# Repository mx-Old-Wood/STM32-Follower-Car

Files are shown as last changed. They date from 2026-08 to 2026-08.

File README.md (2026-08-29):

# STM32 双车跟随小车

基于 STM32F103C8T6 的双车协同跟随项目。本仓库收录从车控制固件、STM32 控制板和双路 DRV8701 电机驱动板设计，覆盖红外循迹、车辆测距、双车通信、串级闭环调速及分阶段超车控制。

## 实物展示

<p align="center">
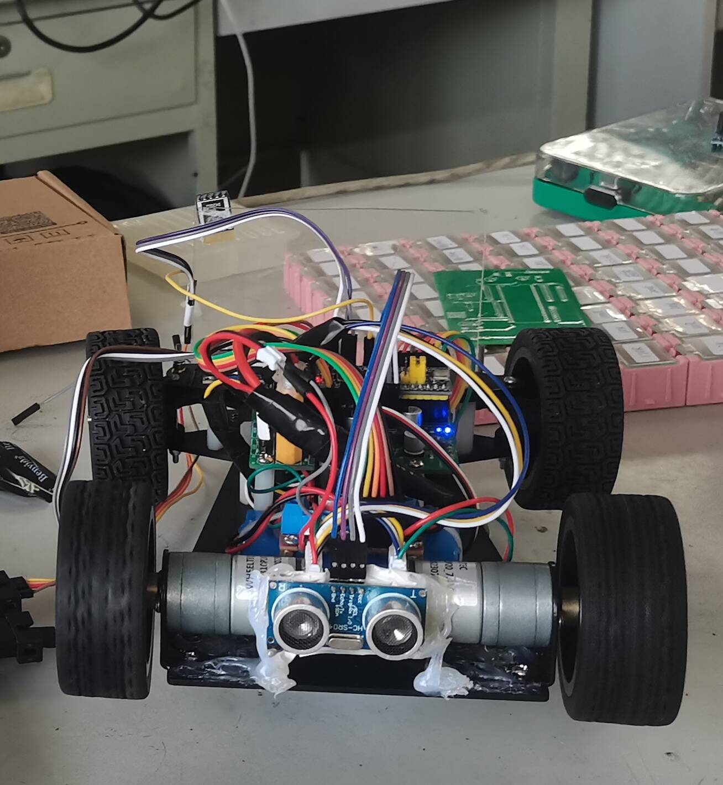
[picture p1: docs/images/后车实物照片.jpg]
STM32 双车跟随小车后车实物
  
</p>

<p align="center">后车实物照片</p>

## 项目概览

从车通过五路红外传感器识别赛道，通过本车超声波或另一辆车发送的距离信息确定跟车速度。距离 P 控制器生成直行速度设定值，双路编码器 PI 控制器进一步调节左右电机 PWM，构成距离外环与速度内环组合的串级控制链路。

模式 2 使用赛道圈数标志 `finish` 描述双车相对位置的变化：从车首先在后方跟随，完成超车后切换为串口距离闭环，另一辆车再次超车后恢复本车超声波闭环。

## 系统架构

```mermaid
flowchart LR
    IR[五路红外传感器] --> TRACK[循迹与转向决策]
    US[本车超声波] --> SELECT[距离源选择]
    UART[另一辆车串口距离] --> SELECT
    FINISH[finish 阶段标志] --> SELECT
    SELECT --> OUTER[距离 P 外环]
    OUTER --> TARGET[直行速度设定]
    TRACK --> MOTION[运动控制]
    TARGET --> MOTION
    MOTION --> PI[双电机增量式 PI]
    PI --> PWM[PWM / DRV8701]
    PWM --> MOTOR[左右直流电机]
    MOTOR --> ENCODER[编码器测速]
    ENCODER --> PI
```

循迹转向采用固定差速参数，距离外环主要作用于直行阶段的速度设定。

## 功能组成

- 五路红外循迹与赛道标志线识别。
- 本车超声波距离和串口距离双数据源切换。
- `20~400 mm` 距离有效范围判断与异常数据剔除。
- 目标距离 `200 mm` 的距离 P 外环。
- `10 ms` 更新周期的双电机增量式 PI 速度内环。
- 基于 `finish` 阶段标志的跟随、超车与让行速度策略。
- OLED 距离/轮速显示，以及停车状态蜂鸣器提示。

## 控制阶段

| 工作状态 | 距离反馈 | 距离失效时的速度策略 |
| --- | --- | --- |
| 模式 1、模式 3 | 本车超声波 | 基础速度 40 |
| 模式 2，`finish == 0` | 本车超声波 | 基础速度 40 |
| 模式 2，`finish == 1` | 串口距离 | 找到车辆前为 45，找到后为 40 |
| 模式 2，`finish >= 2` | 本车超声波 | 找到车辆前为 35，找到后为 40 |

## 硬件设计

| 板卡 | 主要内容 | 设计资料 |
| --- | --- | --- |
| STM32 控制板 | STM32 核心板接口、电源、红外、超声波、串口、蜂鸣器和电机控制接口 | [原理图](docs/images/主控板原理图.pdf) · [布线图](docs/images/主控板布线图.pdf) · [丝印图](docs/images/主控板丝印图.pdf) |
| 双路 DRV8701 驱动板 | 双路栅极驱动、外置功率 MOSFET、逻辑缓冲、电源稳压和状态指示 | [原理图](docs/images/驱动板原理图.pdf) · [布线图](docs/images/驱动板布线图.pdf) · [丝印图](docs/images/驱动板丝印图.pdf) |

Altium Designer 源文件分别位于 [控制板目录](hardware/controller-board/README.md) 和 [驱动板目录](hardware/dual-drv8701/README.md)。

## 软件结构

```text
firmware/follower/
├─ User/                主循环、模式切换与距离控制
├─ Hardware/            红外、超声波、编码器、电机、串口和显示驱动
├─ System/PID/          双电机增量式 PI
├─ System/Timer/        超声波计时、轮速计算和控制周期调度
├─ Library/             STM32F10x 标准外设库
└─ Project.uvprojx      Keil uVision 工程
```

## 构建与验证

| 项目 | 配置 |
| --- | --- |
| MCU | STM32F103C8T6 |
| IDE | Keil uVision 5.41 |
| 编译器 | ARM Compiler 5.06 update 5 (build 528) |
| Device Pack | STM32F1xx DFP 2.2.0 |
| 工程目标 | `Target 1` |
| 构建结果 | `0 Error(s), 0 Warning(s)` |

当前版本完成了源码和工程配置的全量编译验证。原项目曾用于实车开发，但整理后的版本因缺少现有实物，尚未重新执行距离切换、超车动作、电机方向和控制参数的硬件回归测试。

## 文档

- [控制设计](docs/control-design.md)
- [串口通信协议](docs/serial-protocol.md)
- [硬件设计资料](docs/images/README.md)
- [构建验证记录](docs/build-verification.md)
- [设计边界与已知限制](docs/known-limitations.md)
- [第三方内容声明](THIRD_PARTY_NOTICES.md)

## 项目边界

仓库中的生产文件未作为已验证投产资料发布；PCB 下单前仍需结合实际元件、板厂工艺和电气要求重新完成 ERC、DRC、BOM 与封装核对。项目源码和硬件资料当前未统一授予开源许可证。

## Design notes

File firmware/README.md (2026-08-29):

# 从车固件

从车固件面向 STM32F103C8T6，基于 STM32F10x Standard Peripheral Library 开发，并使用 Keil ARM Compiler 5 构建。控制程序同时处理红外循迹、超声波测距、串口通信、距离控制和双电机速度闭环。

## 执行流程

```text
串口接收与显示
      ↓
停车条件与距离控制
      ↓
循迹模式选择
      ↓
运动指令与轮速设定
      ↓
TIM4 周期执行双电机 PI
```

## 模块划分

| 路径 | 功能 |
| --- | --- |
| `follower/User/main.c` | 外设初始化与主循环 |
| `follower/User/Mode.c` | 数据解析、距离源切换、距离控制与停车判断 |
| `follower/Hardware/Infrared.c` | 五路红外循迹、标志线和阶段计数 |
| `follower/Hardware/Ultrasound.c` | 本车超声波触发与距离计算 |
| `follower/Hardware/Serial.c` | USART1 固定帧收发 |
| `follower/Hardware/Encoder.c` | 双路编码器脉冲计数 |
| `follower/System/PID/` | 双电机增量式 PI |
| `follower/System/Timer/Timer.c` | 测距计时、轮速计算和速度环调度 |

## 工程配置

固件工程文件为 `follower/Project.uvprojx`，目标器件为 STM32F103C8，构建目标为 `Target 1`。当前公开版本的全量构建结果为 `0 Error(s), 0 Warning(s)`。

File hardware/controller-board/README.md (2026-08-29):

# STM32 从车控制板

控制板承担传感器接入、双车通信、执行器控制和电源分配，是从车控制系统的信号汇聚节点。板卡通过 STM32F103C8 核心板接口连接主控，并将电机驱动、循迹、测距和人机显示模块集中到统一硬件平台。

## 电路组成

- STM32F103C8 核心板与调试接口。
- 红外循迹、超声波和编码器接口。
- USART 双车通信接口。
- 双路电机驱动控制信号接口。
- 舵机、OLED、蜂鸣器和 LED 接口。
- 板载稳压与电源输入电路。

## 设计文件

| 类型 | 文件 |
| --- | --- |
| Altium 工程 | `source/Control board from the owner_Project.PrjPcb` |
| 原理图 | `source/STM32 Core board.SchDoc` |
| PCB | `source/STM32 Core board.PcbDoc` |
| 原理图库 | `source/STM32 Core board.SCHLIB` |
| PCB 库 | `source/STM32 Core board.PcbLib` |

## PDF 视图

- [控制板原理图](../../docs/images/主控板原理图.pdf)
- [控制板布线图](../../docs/images/主控板布线图.pdf)
- [控制板丝印图](../../docs/images/主控板丝印图.pdf)

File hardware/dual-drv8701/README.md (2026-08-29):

# 双路 DRV8701 电机驱动板

电机驱动板为从车左右直流电机提供独立功率通道。每路通道以 DRV8701E 作为栅极驱动器，配合外置功率 MOSFET 构成电机功率级，并通过逻辑缓冲与控制板连接。

## 电路组成

- 双路 DRV8701E 栅极驱动器。
- 外置功率 MOSFET 电机桥。
- PWM、方向和使能控制接口。
- 逻辑缓冲与信号整形。
- 电机电源输入、板载稳压和状态指示。

## 设计文件

| 类型 | 文件 |
| --- | --- |
| Altium 工程 | `source/DRV8701E.PrjPcb` |
| 原理图 | `source/DRV8901E.SchDoc` |
| PCB | `source/DRV8901E.PcbDoc` |
| 原理图库 | `source/DRV8701_DualMotorDriver.SCHLIB` |
| PCB 库 | `source/DRV8701_DualMotorDriver V1.1.PcbLib` |

源文件中的 `DRV8901E` 为历史文件名，板卡实际采用的核心驱动器为 DRV8701E。文件名保持不变，以维持 Altium 工程内部引用关系。

## PDF 视图

- [驱动板原理图](../../docs/images/驱动板原理图.pdf)
- [驱动板布线图](../../docs/images/驱动板布线图.pdf)
- [驱动板丝印图](../../docs/images/驱动板丝印图.pdf)

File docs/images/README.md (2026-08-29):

# 硬件设计资料

本目录收录 STM32 控制板与双路 DRV8701 电机驱动板的 PDF 设计视图，用于在不安装 Altium Designer 的情况下查看原理图、PCB 布线和顶层丝印。

## STM32 控制板

| 文档 | 内容 |
| --- | --- |
| [主控板原理图](主控板原理图.pdf) | 控制核心、电源及外设接口连接 |
| [主控板布线图](主控板布线图.pdf) | PCB 器件布局、焊盘和走线 |
| [主控板丝印图](主控板丝印图.pdf) | 顶层丝印、接口标识和板框 |

## 双路 DRV8701 驱动板

| 文档 | 内容 |
| --- | --- |
| [驱动板原理图](驱动板原理图.pdf) | 双路电机驱动、电源与逻辑接口 |
| [驱动板布线图](驱动板布线图.pdf) | PCB 器件布局、功率回路和焊盘 |
| [驱动板丝印图](驱动板丝印图.pdf) | 顶层丝印、接口标识和板框 |

对应的可编辑 Altium Designer 文件位于 `hardware/controller-board/source/` 和 `hardware/dual-drv8701/source/`。

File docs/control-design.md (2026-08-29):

# 控制系统设计

## 总体结构

从车控制系统由循迹控制、距离外环和轮速内环组成。五路红外传感器负责赛道方向判断；距离反馈用于生成直行速度设定；双路编码器 PI 控制器将速度设定转换为电机 PWM 输出。

```text
超声波/串口距离 -> 距离 P 外环 -> 速度设定 -> 编码器 PI 内环 -> PWM -> 电机
五路红外传感器 -----------------> 转向与差速控制 ---------> 电机
```

距离外环作用于直行跟随阶段。转弯和循迹修正采用固定的左右轮差速参数，以保持原项目的赛道运行特性。

## 距离反馈选择

| 条件 | 相对位置 | 距离来源 | 控制方向 |
| --- | --- | --- | --- |
| 模式 1、模式 3 | 普通跟随 | 本车超声波 | 距离增大时加速 |
| 模式 2，`finish == 0` | 本车在后 | 本车超声波 | 距离增大时加速 |
| 模式 2，`finish == 1` | 本车在前 | 串口距离 | 距离增大时减速 |
| 模式 2，`finish >= 2` | 本车重新在后 | 本车超声波 | 距离增大时加速 |

阶段变化时，控制程序清除对应距离有效标志和 `Car_Found`，避免上一阶段的测距结果直接参与新阶段控制。

## 距离外环

距离控制参数定义于 `firmware/follower/User/Mode.h`：

| 参数 | 数值 | 含义 |
| --- | ---: | --- |
| `DISTANCE_MIN` | 20 mm | 有效距离下限 |
| `DISTANCE_MAX` | 400 mm | 有效距离上限 |
| `DISTANCE_AIM` | 200 mm | 目标跟车距离 |
| `BASE_SPEED` | 40 | 基础速度设定 |
| `MIN_SPEED` | 32 | 闭环速度下限 |
| `MAX_SPEED` | 45 | 闭环速度上限 |
| `DISTANCE_KP` | 0.07 | 距离比例系数 |

本车位于后方时，距离外环采用正向速度补偿：

```text
Speed_Set = 40 + 0.07 * (Local_Distance - 200)
```

本车位于前方时，串口距离表示后车与本车之间的间距，控制方向相反：

```text
Speed_Set = 40 - 0.07 * (Remote_Distance - 200)
```

两种计算结果均限制在 `32~45`。本车超声波距离有效且不大于 `180 mm` 时，运动控制切换为停车状态。

## 异常距离策略

距离数据只在 `20~400 mm` 范围内参与闭环。范围外数据不会更新当前有效距离，其对应速度策略如下：

| 场景 | 备用速度 |
| --- | ---: |
| 普通跟随阶段 | 40 |
| 第一次超车阶段，尚未检测到另一辆车 | 45 |
| 第二次让行阶段，尚未检测到另一辆车 | 35 |
| 当前阶段已经检测到车辆后再次丢失距离 | 40 |

该策略用于降低弯道中超声波偏转对速度设定的直接影响。

## 速度内环

TIM4 以 `100 us` 为中断周期，每累计 100 次中断完成一次轮速计算和 PI 更新，因此速度环周期为 `10 ms`。左右电机分别维护独立的增量式 PI 状态。

| 参数 | 数值 |
| --- | ---: |
| `Kp` | 1.85 |
| `Ki` | 0.40 |
| `Kd` | 0 |
| 输出范围 | `-65~65` |

速度设定为 0 时，电机 PWM、PI 输出和历史误差同步清零，停车状态不继续累积控制量。

## 关键实现位置

| 文件 | 职责 |
| --- | --- |
| `User/Mode.c` | 距离解析、阶段切换、距离控制和停车判断 |
| `Hardware/Infrared.c` | 循迹、标志线识别和 `finish` 更新 |
| `System/PID/PID.c` | 增量式 PI 运算 |
| `System/PID/Speed_Control.c` | 双电机速度控制与零速处理 |
| `System/Timer/Timer.c` | 编码器采样、轮速计算和速度环调度 |

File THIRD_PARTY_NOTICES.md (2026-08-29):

# 第三方内容声明

本仓库包含来自第三方固件发行包和通用 STM32 教学示例的代码。相关文件保留其原始版权声明，并继续受原权利人的许可条款约束。

## STMicroelectronics 与 ARM

以下目录和文件包含 STM32F10x Standard Peripheral Library、CMSIS、设备支持、启动文件或工程模板内容：

- `firmware/follower/Library/`
- `firmware/follower/Start/`
- `firmware/follower/User/stm32f10x_conf.h`
- `firmware/follower/User/stm32f10x_it.c`
- `firmware/follower/User/stm32f10x_it.h`

上述内容的版权归 STMicroelectronics、ARM 或相应权利人所有，不因收录于本仓库而改变授权方式。

## 外设驱动代码

部分基础外设驱动源于常见 STM32 教学示例。仓库未对这些第三方内容进行统一再授权。带有额外限制声明且未被当前工程使用的 `System/Sys` 和 `System/Usart` 已从公开副本中移除。

项目自编控制逻辑与第三方基础库在目录结构中保持分离，便于识别各自来源与适用许可。

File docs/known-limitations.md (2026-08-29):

# 设计边界与已知限制

本项目以完成双车循迹、跟随和超车实验为目标，控制结构保留了入门阶段的直接实现方式。

## 软件结构

- 循迹转弯采用阻塞式 `while` 判断，转向动作期间的任务调度能力有限。
- 转弯过程不主动更新本车超声波，距离控制可能短暂沿用上一轮采样结果。
- `finish` 由标志线识别累加并通过复位清零，不包含掉电保存和异常恢复。
- 超车和让行采用固定速度与赛道经验参数，不包含轨迹规划。

## 数据可靠性

- 超声波和串口距离仅进行 `20~400 mm` 范围判断，没有连续确认或数字滤波。
- 串口距离没有超时失效机制，通信停止后可能保留上一帧有效状态。
- 串口解析未加入长度、非数字字符、缓冲区边界和校验和检查。

## 验证范围

- 固件已通过 Keil 全量编译，结果为 `0 Error(s), 0 Warning(s)`。
- 原始版本曾用于实车开发；当前整理版本没有完成最新硬件回归测试。
- PCB 源文件和 PDF 设计资料用于项目展示，未作为经过复核的量产文件发布。

这些边界限定了当前版本的适用范围，也构成后续非阻塞状态机、通信超时、距离滤波和参数整定功能的演进基础。

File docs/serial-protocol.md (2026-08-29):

# 双车串口通信协议

## 接口配置

| 参数 | 配置 |
| --- | --- |
| 波特率 | 115200 |
| 数据位 | 8 |
| 校验位 | None |
| 停止位 | 1 |
| 流控制 | None |

## 帧格式

双车通信采用固定长度 ASCII 数据帧：

```text
@DDDDMMSS\r\n
```

| 字段 | 长度 | 定义 |
| --- | ---: | --- |
| `@` | 1 | 帧头 |
| `DDDD` | 4 | 另一辆车发送的距离，单位 mm |
| `MM` | 2 | 工作模式 |
| `SS` | 2 | 运行状态标志 |
| `\r\n` | 2 | 帧尾 |

示例帧：

```text
@02000201\r\n
```

该帧表示距离 `200 mm`、模式 `2`、状态值 `1`。

## 接收流程

USART1 中断以 `@` 作为接收起点，以 `\r\n` 作为结束标志。完整帧到达后置位接收标志，上层按照 `4 + 2 + 2` 位数字分别解析距离、模式和状态。

串口距离位于 `20~400 mm` 时标记为有效。控制程序同时根据状态字段执行以下动作：

| 条件 | 行为 |
| --- | --- |
| `Stop == 2` | 电机停止，持续等待新状态 |
| `Stop == 0`、距离有效且 `Remote_Distance <= 250` | 电机停止，蜂鸣器开启 |
| 其他状态 | 进入距离控制与循迹流程 |

## 协议边界

当前协议面向固定格式、低通信负载的双车实验场景，没有加入校验和、序号、字段类型检查和接收超时。发送端与接收端使用相同的固定帧定义。

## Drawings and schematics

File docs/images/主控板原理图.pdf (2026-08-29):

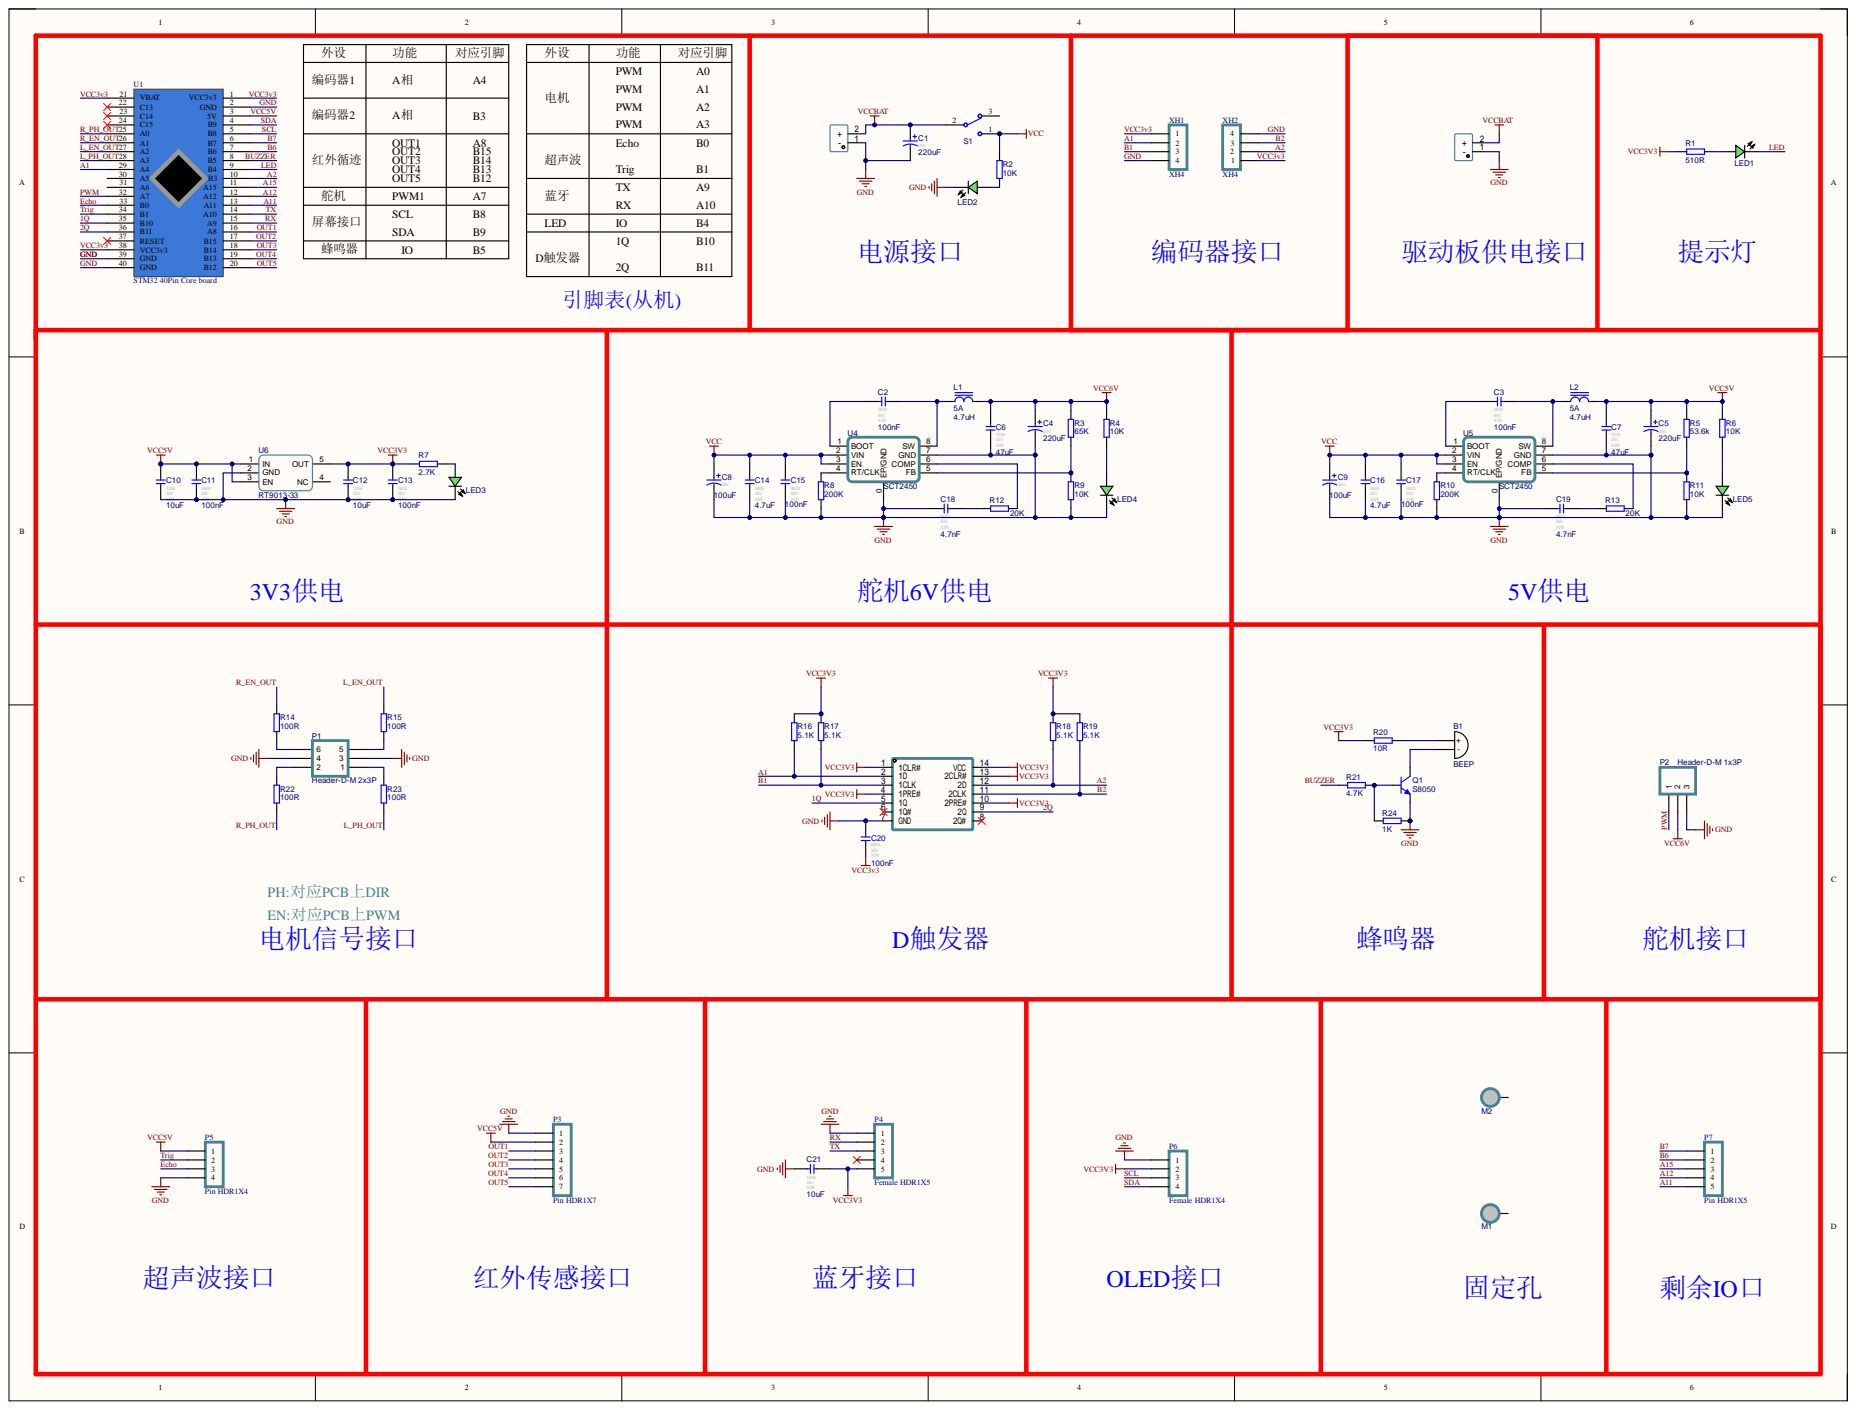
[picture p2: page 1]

Comment | Description | Designator | Footprint | LibRef | Quantity
BEEP | 蜂鸣器 | B1 | BEEP 9x5.5mm | BEEP | 1
220uF 25V 铝电解 | 贴片电解电容 220uF 25V 6.3x7.7 | C1, C4, C5 | CAP-E-S 6.3 | E-S 220uF 25V 6.3x7.7 | 3
100nF 50V X7R | 贴片瓷片电容; MLCC; 0603(1608); | C2, C3, C11, C13, C15, C17, C20 | C0805 | 100nF 0603 50V X7R | 7
47uF 25V X5R | 贴片瓷片电容; MLCC; 1206(3216); | C6, C7 | C0805 | 47uF 1206 25V X5R | 2
100uF 35V 铝电解 | 贴片电解电容 100uF 35V 6.3x7.7 | C8, C9 | CAP-E-S 6.3 | E-S 100uF 35V 6.3x7.7 | 2
10uF 25V X5R | 贴片瓷片电容; MLCC; 1206(3216); | C10, C12 | C0805 | 47uF 1206 25V X5R | 2
4.7uF 35V X5R | 贴片瓷片电容; MLCC; 1206(3216); | C14, C16 | C0805 | 4.7uF 1206 35V X5R | 2
4.7nF 50V X7R | 贴片瓷片电容; MLCC; 0603(1608); | C18, C19 | C0805 | 4.7nF 0603 50V X7R | 2
10uF 35V X5R | 贴片瓷片电容; MLCC; 1206(3216); | C21 | CAPC3216[1206]S | 4.7uF 1206 35V X5R | 1
4.7uH 5A | 功率电感 | L1, L2 | 0630 TPC 7*7*3 | Ind-Power | 2
翠绿贴片LED | 翠绿贴片LED | LED1, LED2, LED3, LED4, LED5 | LED_0805 | LED Chip Green | 5
Header-D-M 2x3P | 2x3pin, 直插, 双排针 | P1 | HDR2X3-M | Header-D-M 2x3P | 1
Header-D-M 1x3P | 1x3pin, 直插, 排针 | P2 | HDR1X3-M | Header-D-M 1x3P | 1
Pin HDR1X7 | | P3 | Pin HDR1X7/2.54mm-S | Pin HDR1X7 | 1
Female HDR1X5 | | P4 | Fe-HDR1X5/2.54-S | Female HDR1X5 | 1
Pin HDR1X4 | | P5 | Pin HDR1X4/2.54mm-S | Pin HDR1X4 | 1
Female HDR1X4 | | P6 | Fe-HDR1X4/2.54-S | Female HDR1X4 | 1
Pin HDR1X5 | | P7 | Pin HDR1X5/2.54mm-S | Pin HDR1X5 | 1
S8050 | NPN 三极管 | Q1 | SOT-23 | NPN S8050 | 1
510R ±1% | 贴片电阻 | R1 | R0805 - duplicate | Res-Chip_9 | 1
10K ±1% | 贴片电阻 | R2, R4, R6, R9, R11 | R0805 - duplicate | Res-Chip | 5
65K ±1% | 贴片电阻 | R3 | R0805 - duplicate | Res-Chip_4 | 1
53.6k ±1% | 贴片电阻 | R5 | R0805 - duplicate | Res-Chip_4 | 1
2.7K ±1% | 贴片电阻 | R7 | R0805 - duplicate | Res-Chip_6 | 1
200K ±1% | 贴片电阻 | R8, R10 | R0805 - duplicate | Res-Chip_1 | 2
20K ±1% | 贴片电阻 | R12, R13 | R0805 - duplicate | Res-Chip_4 | 2
100R ±1% | 贴片电阻 | R14, R15, R22, R23 | R0805 - duplicate | Res-Chip_9 | 4
5.1K ±1% | 贴片电阻 | R16, R17, R18, R19 | R0805 - duplicate | Res-Chip_3 | 4
10R ±1% | 贴片电阻 | R20 | R0805 - duplicate | Res-Chip_10 | 1
4.7K ±1% | 贴片电阻 | R21 | R0805 - duplicate | Res-Chip_3 | 1
1K ±1% | 贴片电阻 | R24 | R0805 - duplicate | Res-Chip_11 | 1
SW-SPDT | 单刀双掷开关 3脚船 型、钮子、拨动开关 SPDT Subminiature Toggle Switch | S1 | SS12D10 | SW-SPDT | 1
STM32 40Pin Core board | 江协科技 STM32F103C8T6核 心板 | U1 | STM32 Core board | STM32 Core board | 1
XT60 | | U2, U3 | CONN-TH_XT60 | XT60 | 2
SCT2450 | SP1N28STER | U4, U5 | SOP-8E | SP1N28STER | 2
RT9013-33 | 3.3V 500mA SOT-23-5 LDO | U6 | SOT-23-5 | RT9013-33 | 1
SN74HC74D | | U7 | SOIC-14_L8.7-W3.9-P1.27-LS6.0-BL | SN74HC74D | 1
XH4 | | XH1, XH2 | XH4/2.54mm/180 -duplicate | XH4 | 2

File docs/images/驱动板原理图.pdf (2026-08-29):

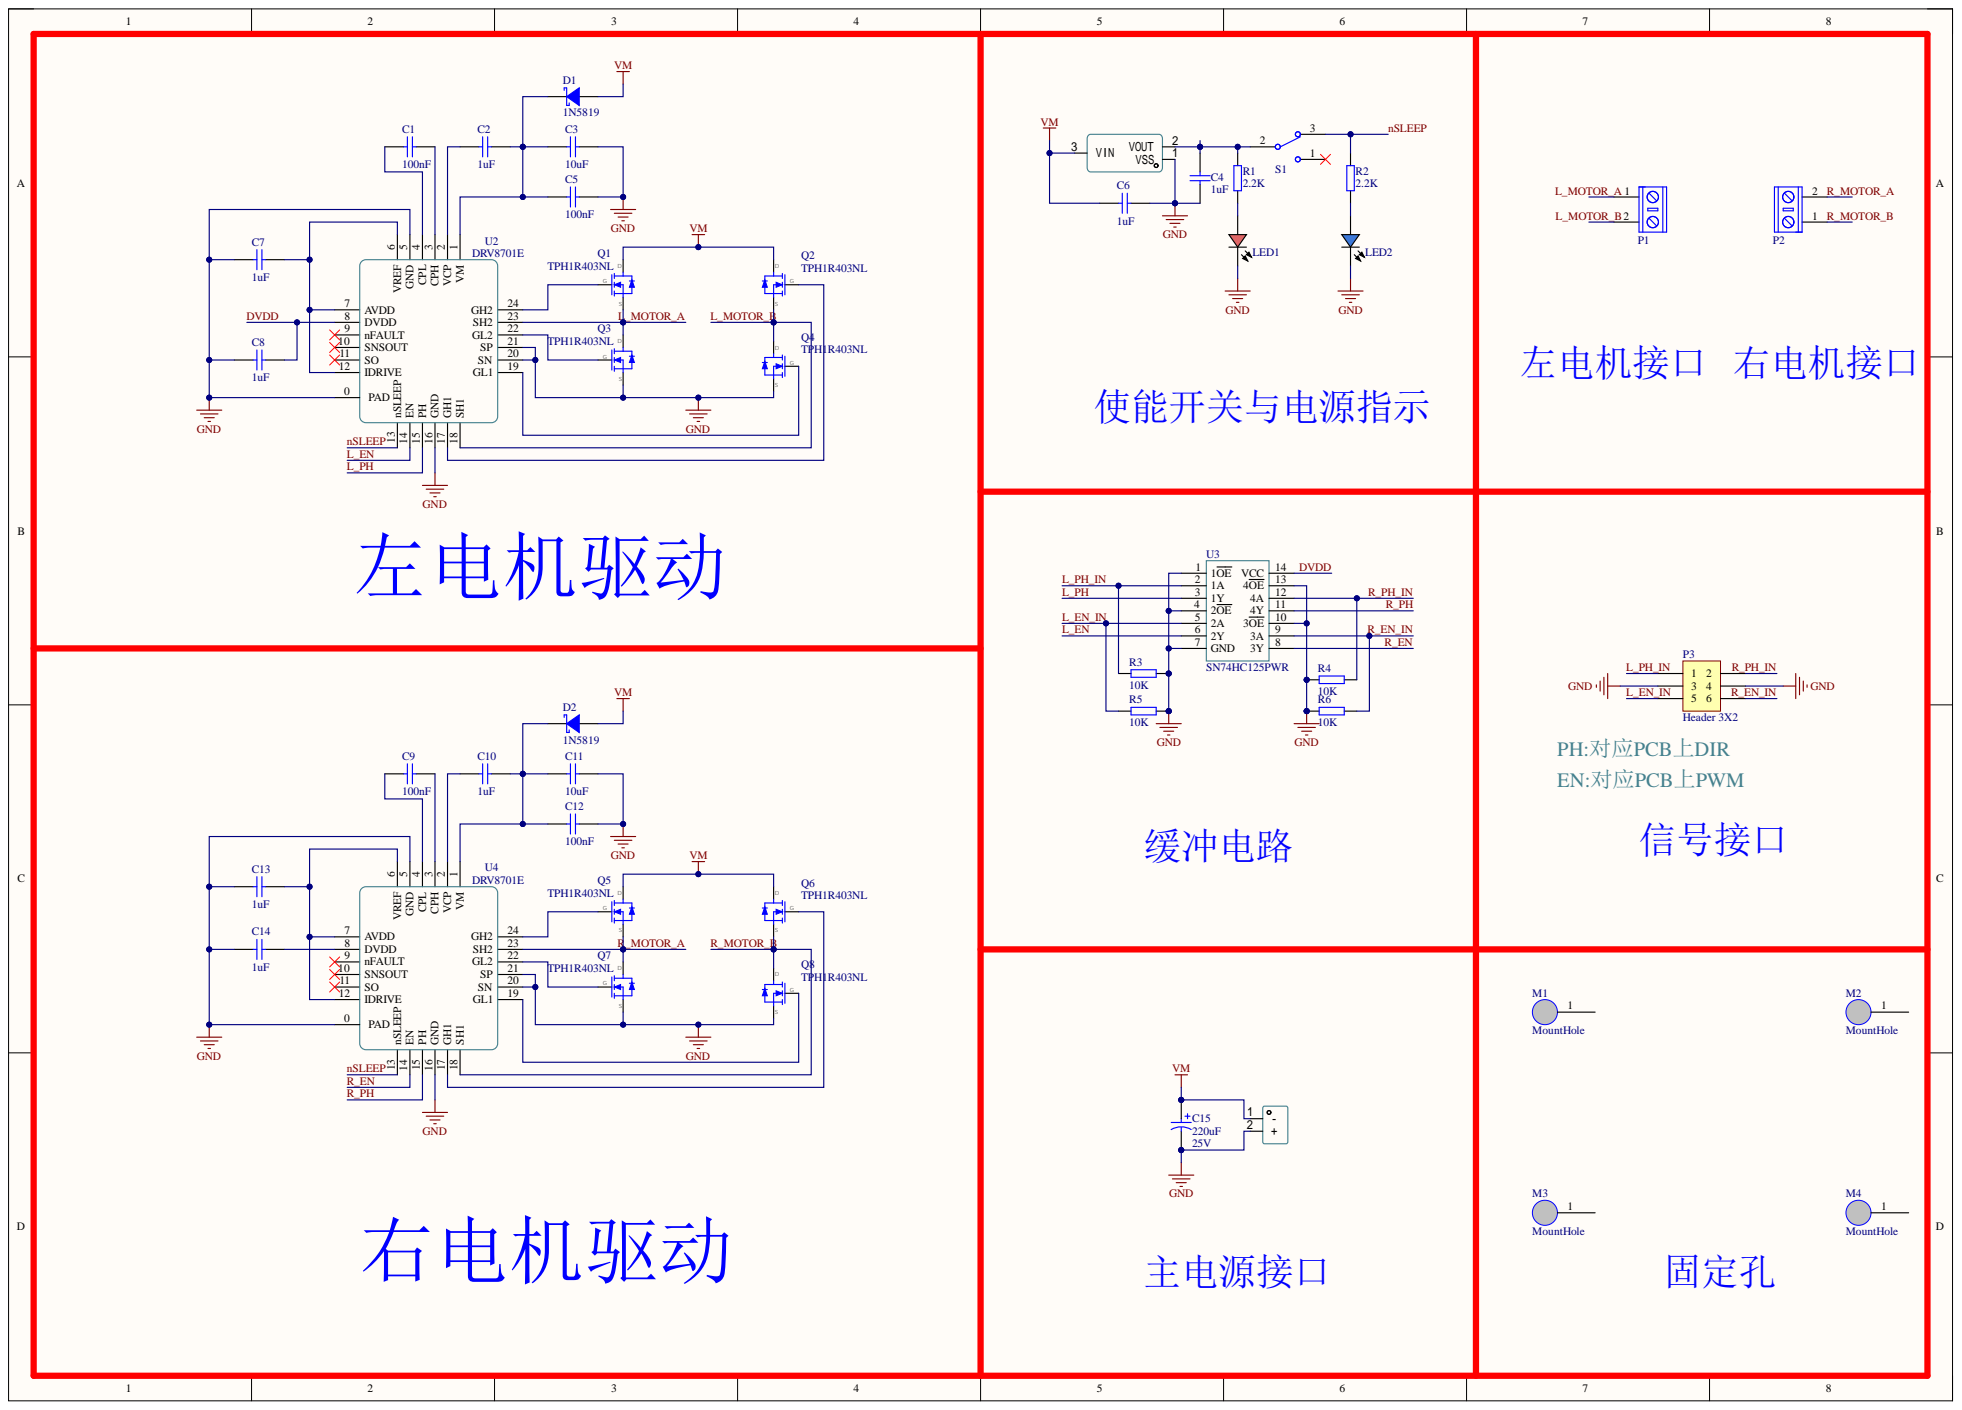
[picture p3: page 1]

VM 1 VCP 2 CPH 3 CPL 4 GND 5 VREF 6 nSLEEP 13

S L_MOTOR_A L_MOTOR_B | S

Comment | Description | Designator | Footprint | LibRef | Quantity
100nF ±10% 50V | 贴片电容 | C1, C5, C9, C12 | CAPC2012[0805]S-N | Cap-Chip_1 | 4
1uF ±10% 25V | 贴片电容 | C2, C4, C6, C7, C8, C10, C13, C14 | CAPC2012[0805]S-N | Cap-Chip_2 | 8
10uF ±10% 25V | 贴片电容 | C3, C11 | CAPC2012[0805]S-N | Cap-Chip | 2
220uF 25V | Polarized Capacitor (Radial) | C15 | CAP-E-S 6.3 | Cap-Elect | 1
1N5819 | 肖特基二极管 Diode | D1, D2 | SOD-123-L | Diode Schottky | 2
| Typical Chip LED | LED1 | LED_0805 | LED Chip Red | 1
Blue | Typical Chip LED | LED2 | LED_0805 | LED Chip Blue | 1
KF/WJ/DG 30x connecter | 接线端子 2Pin | P1, P2 | KF/WJ/DG 301-2p-5.0mm | KF/WJ/DG 30x | 2
Header 3X2 | Header, 3-Pin, Dual row | P3 | HDR2X3 | Header 3X2 | 1
TPH1R403NL | 东芝 N沟 MOS | Q1, Q2, Q3, Q4, Q5, Q6, Q7, Q8 | DFN5x6 | TPH1R403NL | 8
2.2K ±1% | 贴片电阻 | R1, R2 | R0805 | Res-Chip | 2
10K ±1% | 贴片电阻 | R3, R4, R5, R6 | R0805 | Res-Chip_1 | 4
SW-SPDT | 单刀双掷开关 3脚船 型、钮子、拨动开关 SPDT Subminiature Toggle Switch | S1 | SS12D10 | SW-SPDT | 1
LR8341A-T33 | | U1 | SOT-23-3L_L2.9-W1.6-P1.90-LS2.8-BL | LR8341A-T33 | 1
DRV8701E | DRV8701E Ti全桥驱 动芯片 | U2, U4 | QFN24-4x4 | DRV8701E | 2
SN74HC125PWR | 三态输出的四路缓冲 器 TSSOP-20 | U3 | TSSOP-14 | SN74HC125PWR | 1
XT60 | | U5 | CONN-TH_XT60 | XT60 | 1

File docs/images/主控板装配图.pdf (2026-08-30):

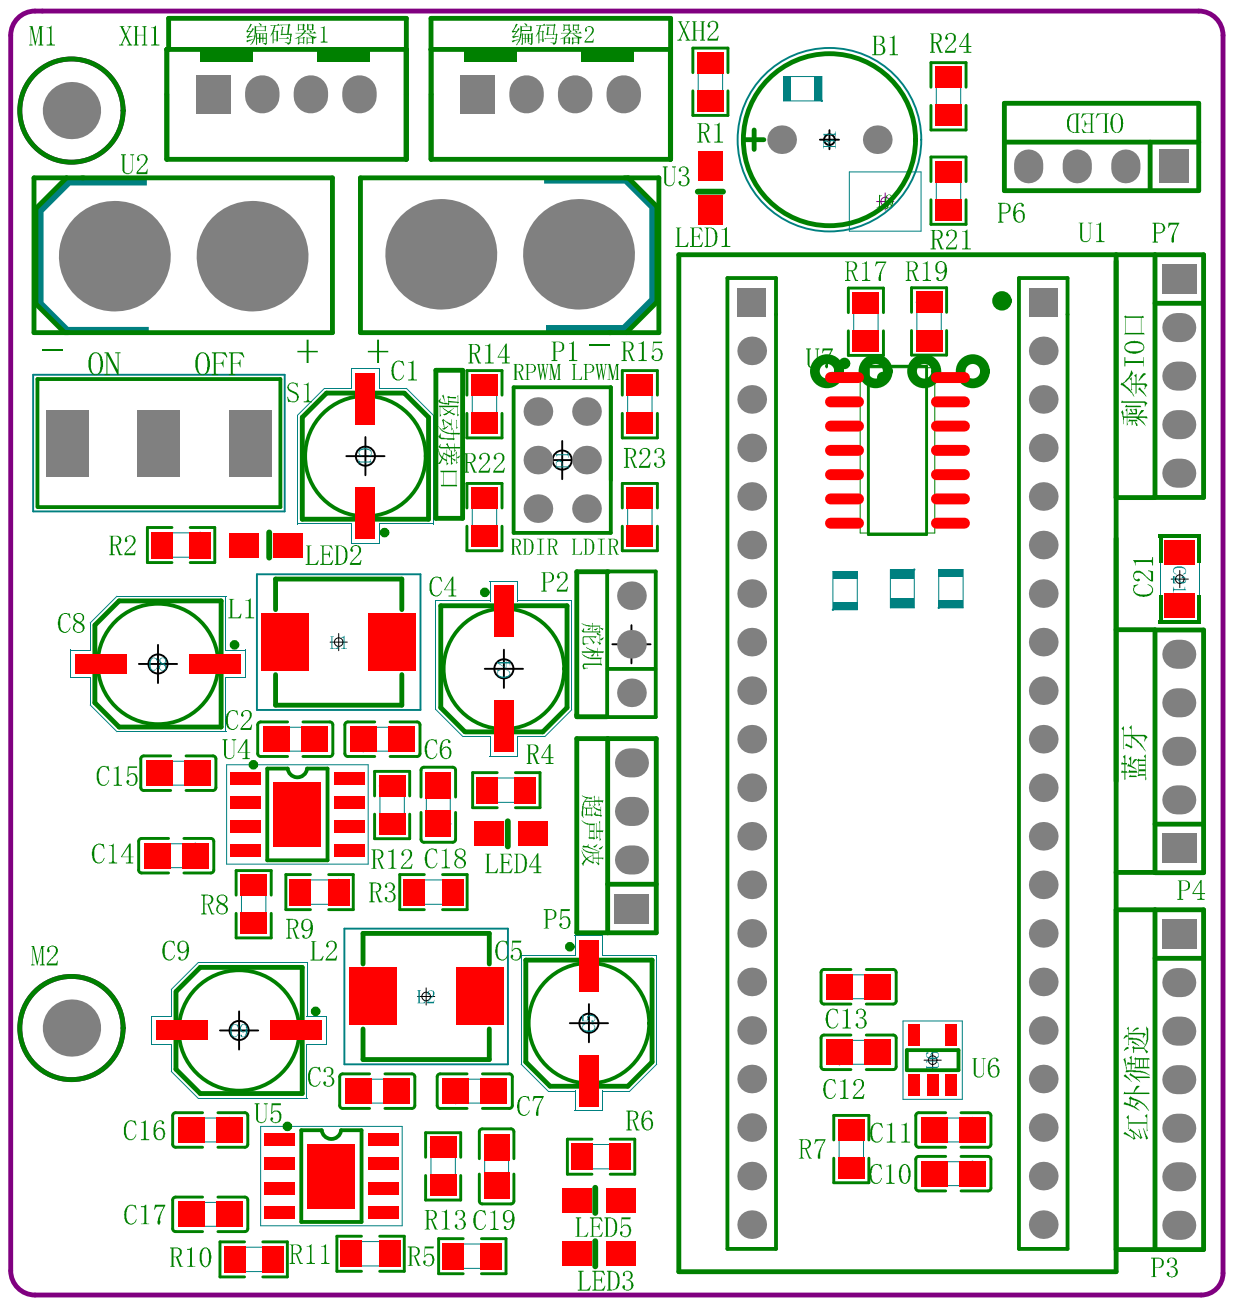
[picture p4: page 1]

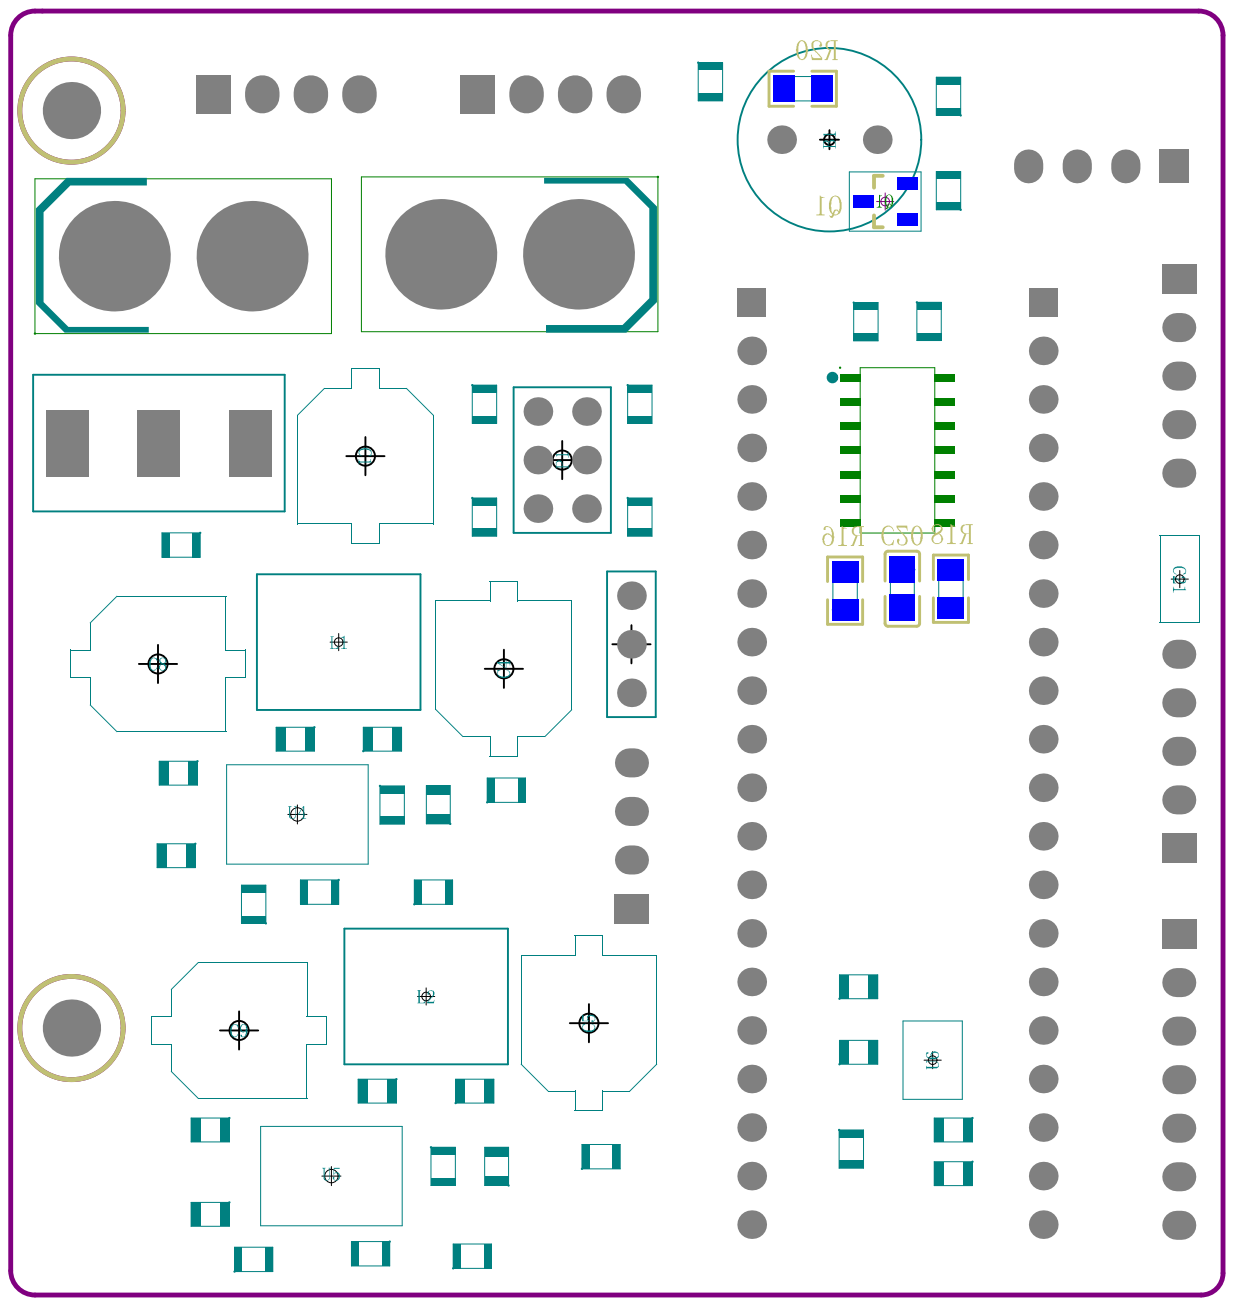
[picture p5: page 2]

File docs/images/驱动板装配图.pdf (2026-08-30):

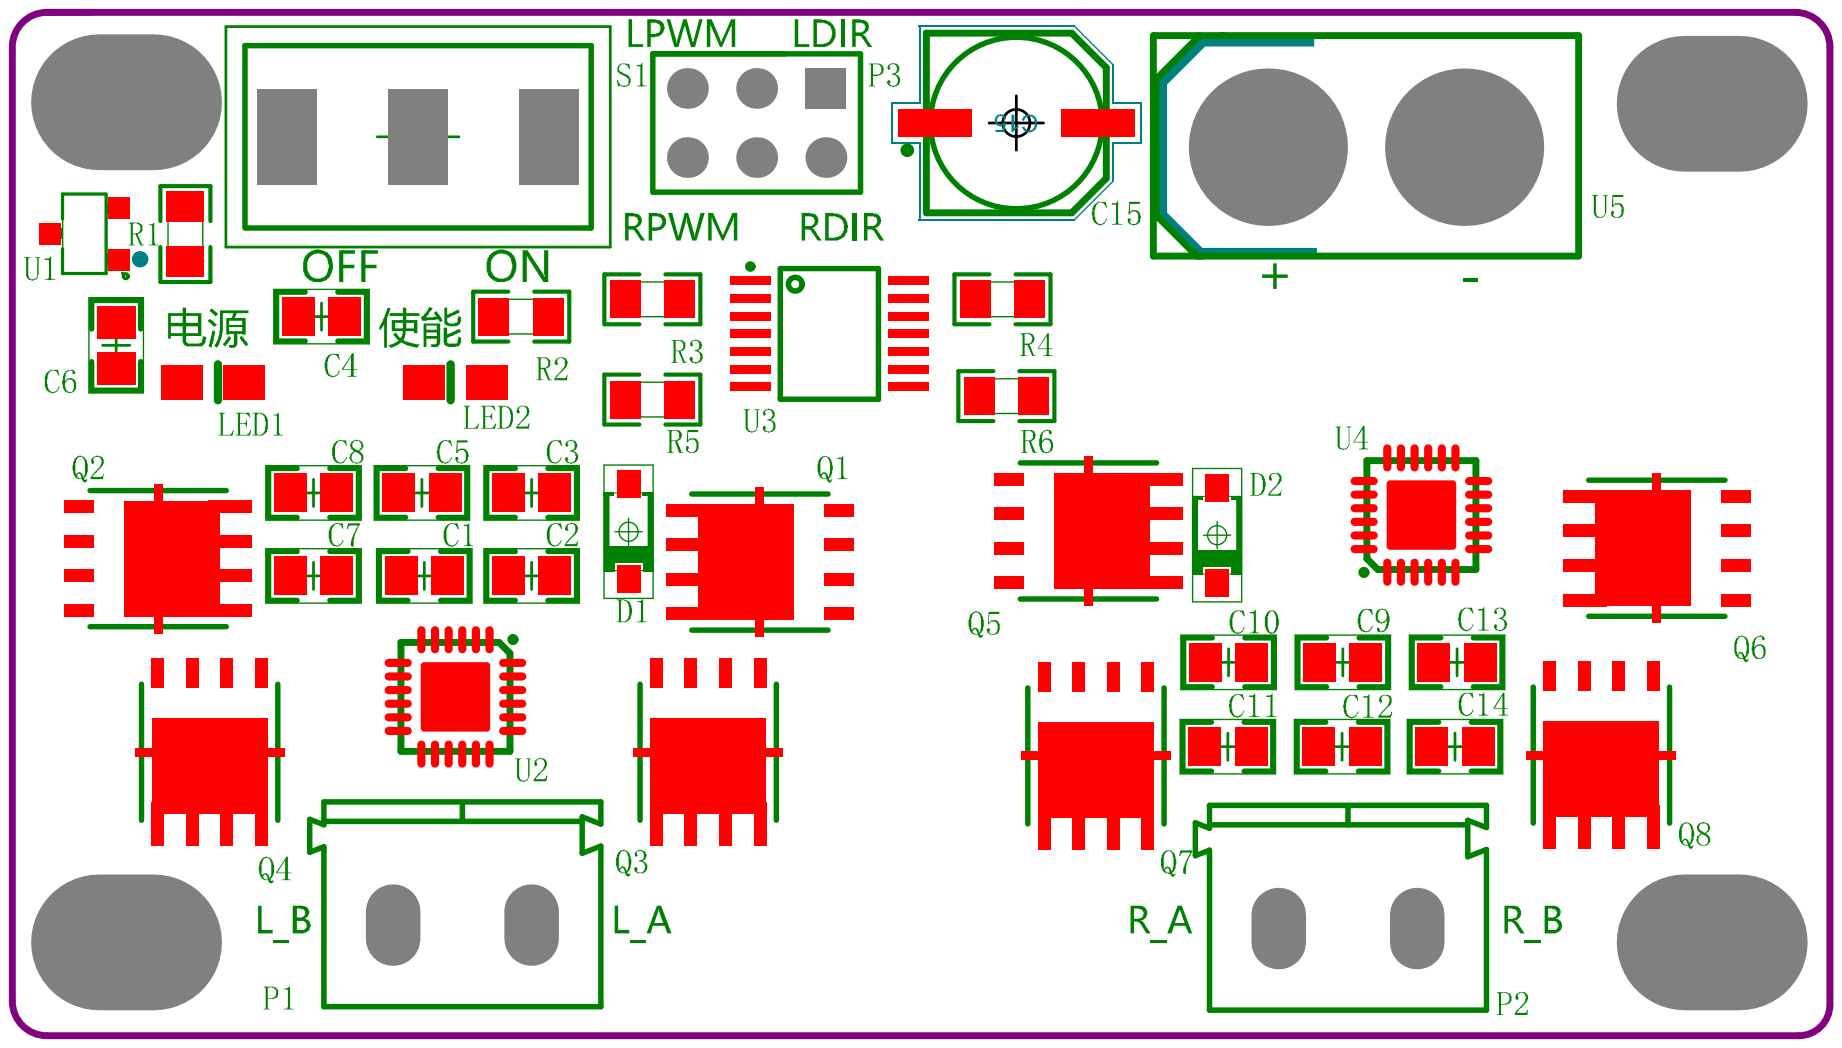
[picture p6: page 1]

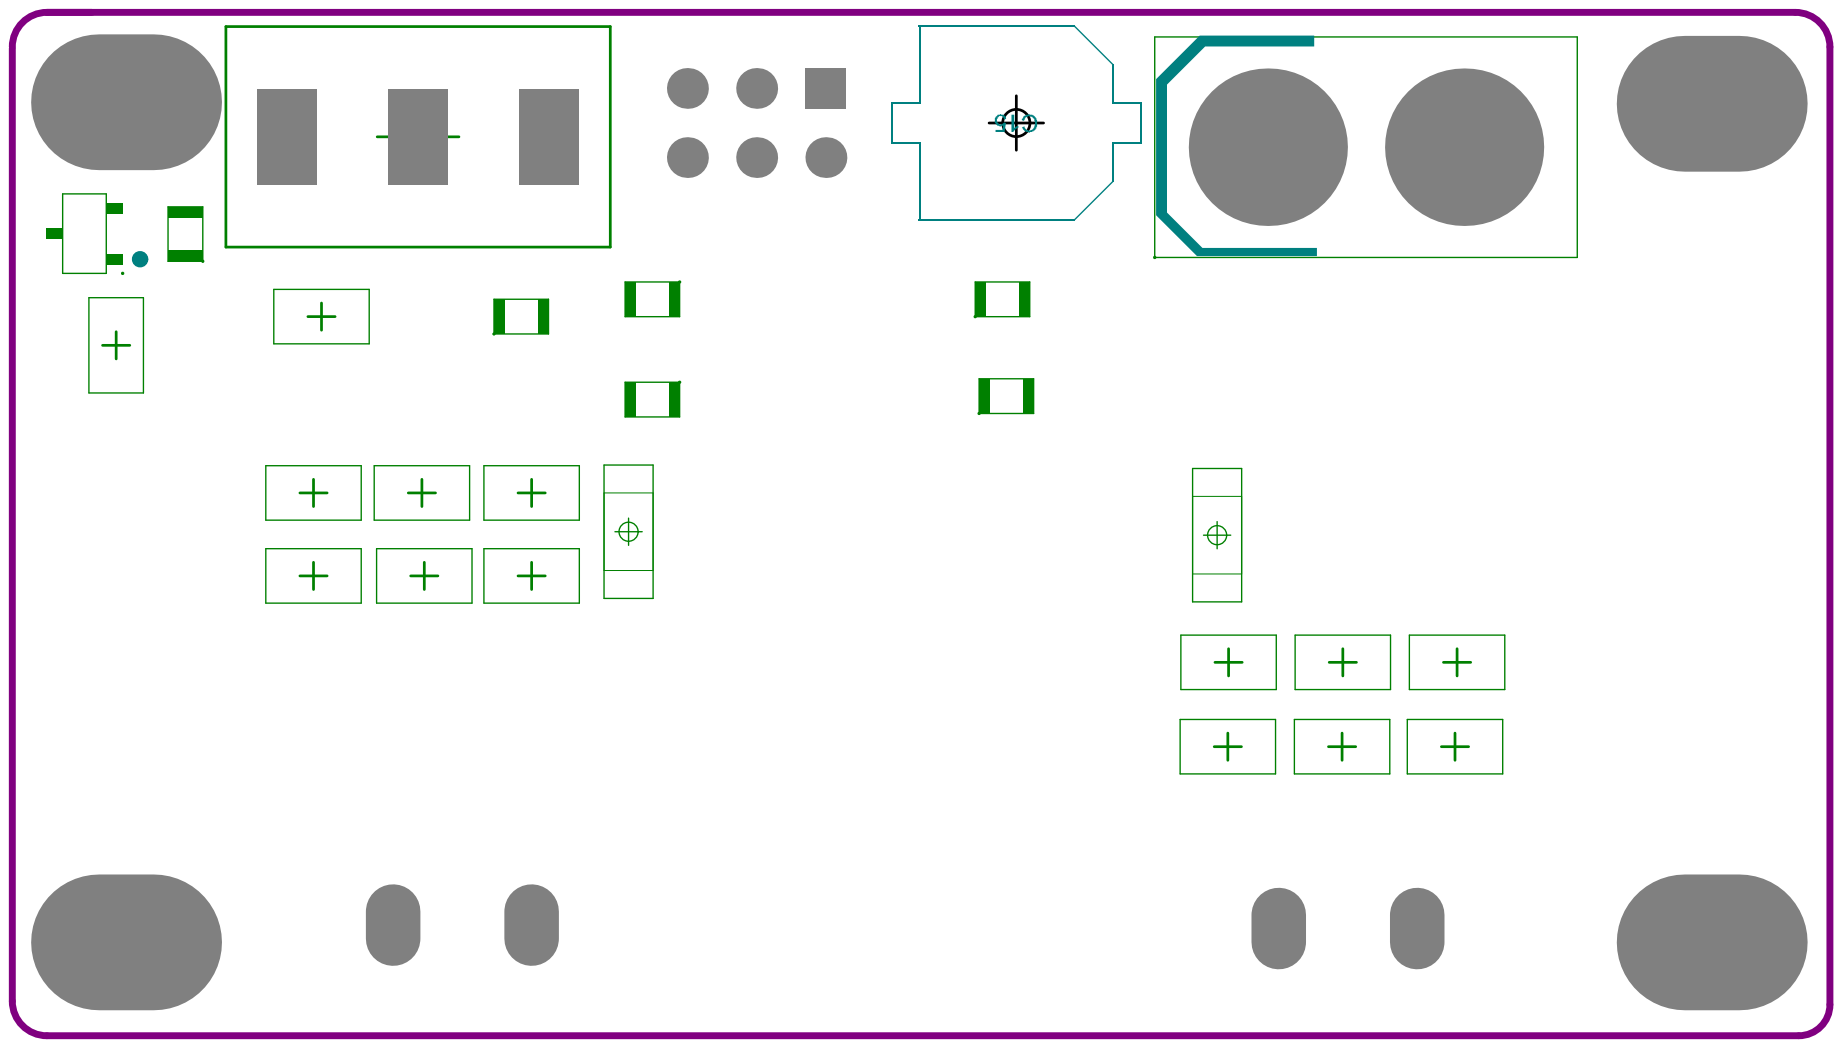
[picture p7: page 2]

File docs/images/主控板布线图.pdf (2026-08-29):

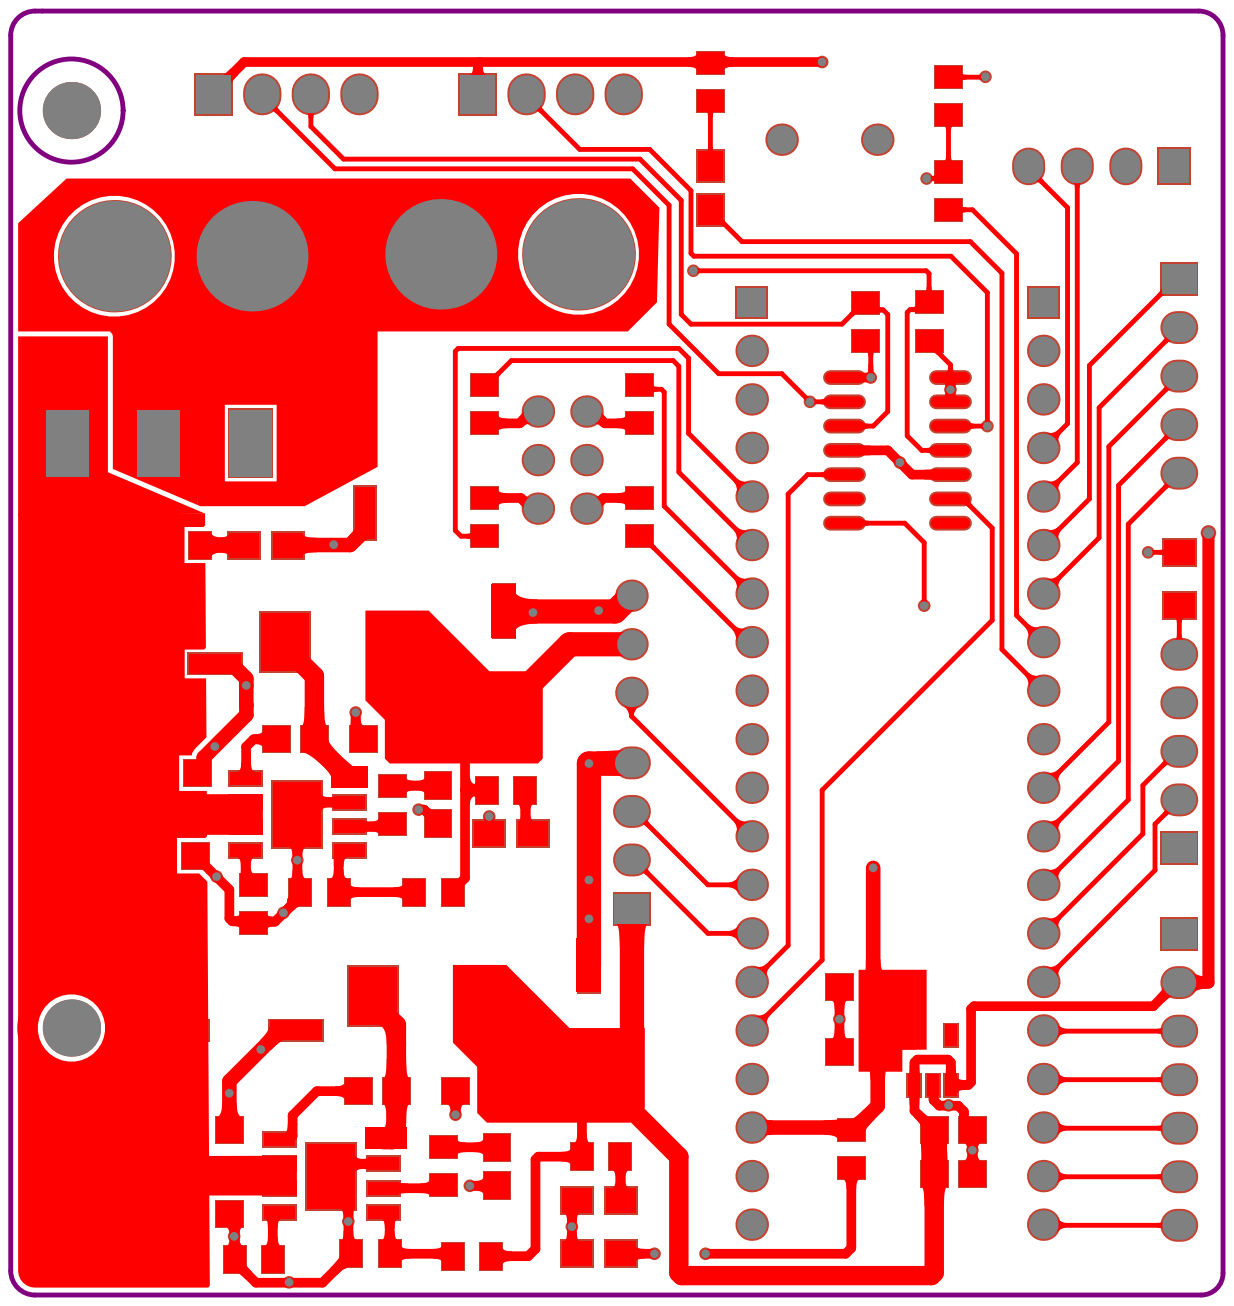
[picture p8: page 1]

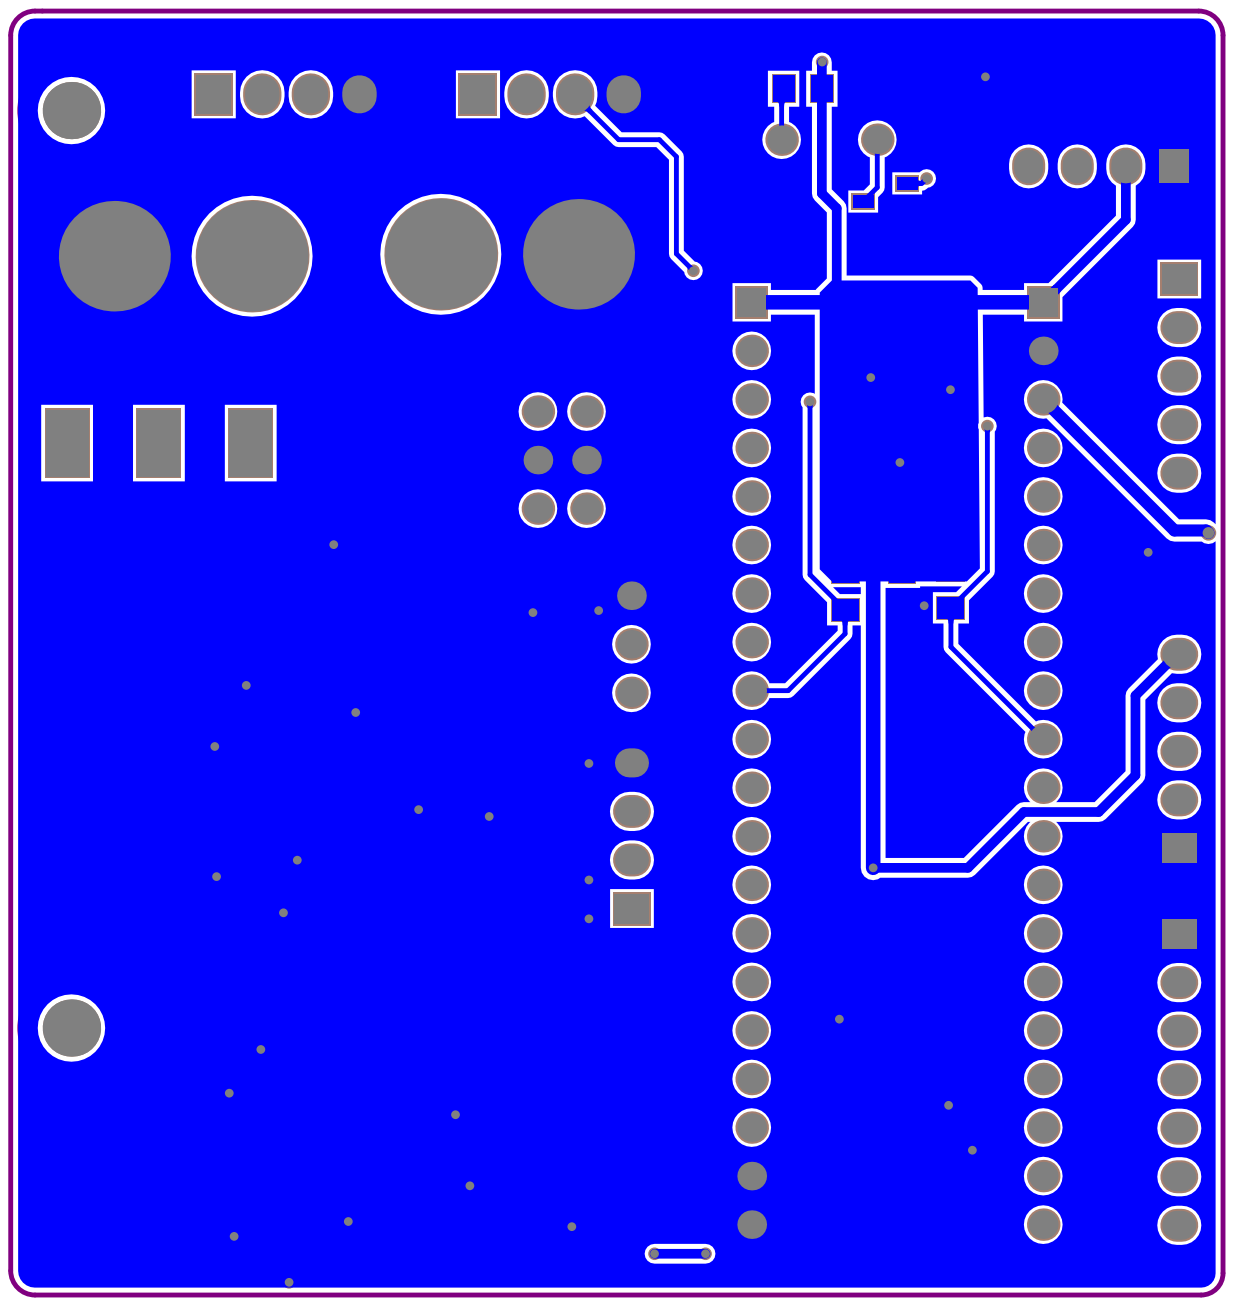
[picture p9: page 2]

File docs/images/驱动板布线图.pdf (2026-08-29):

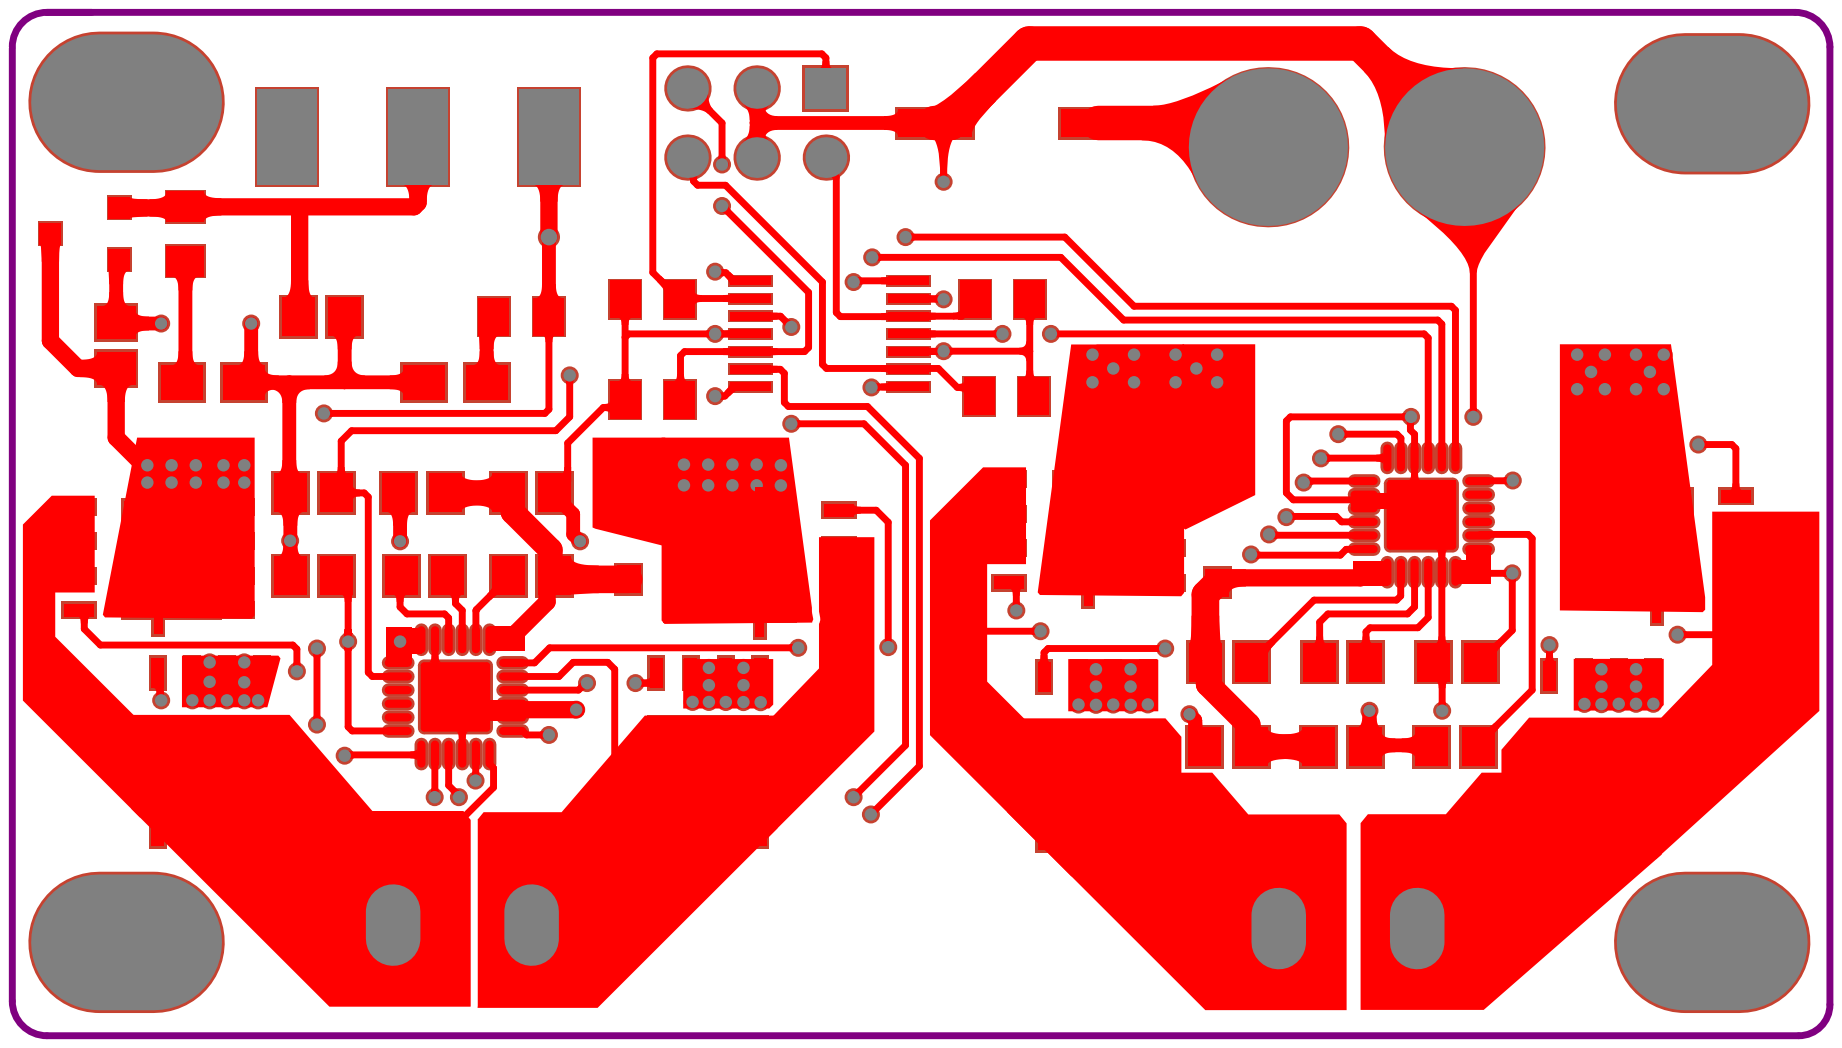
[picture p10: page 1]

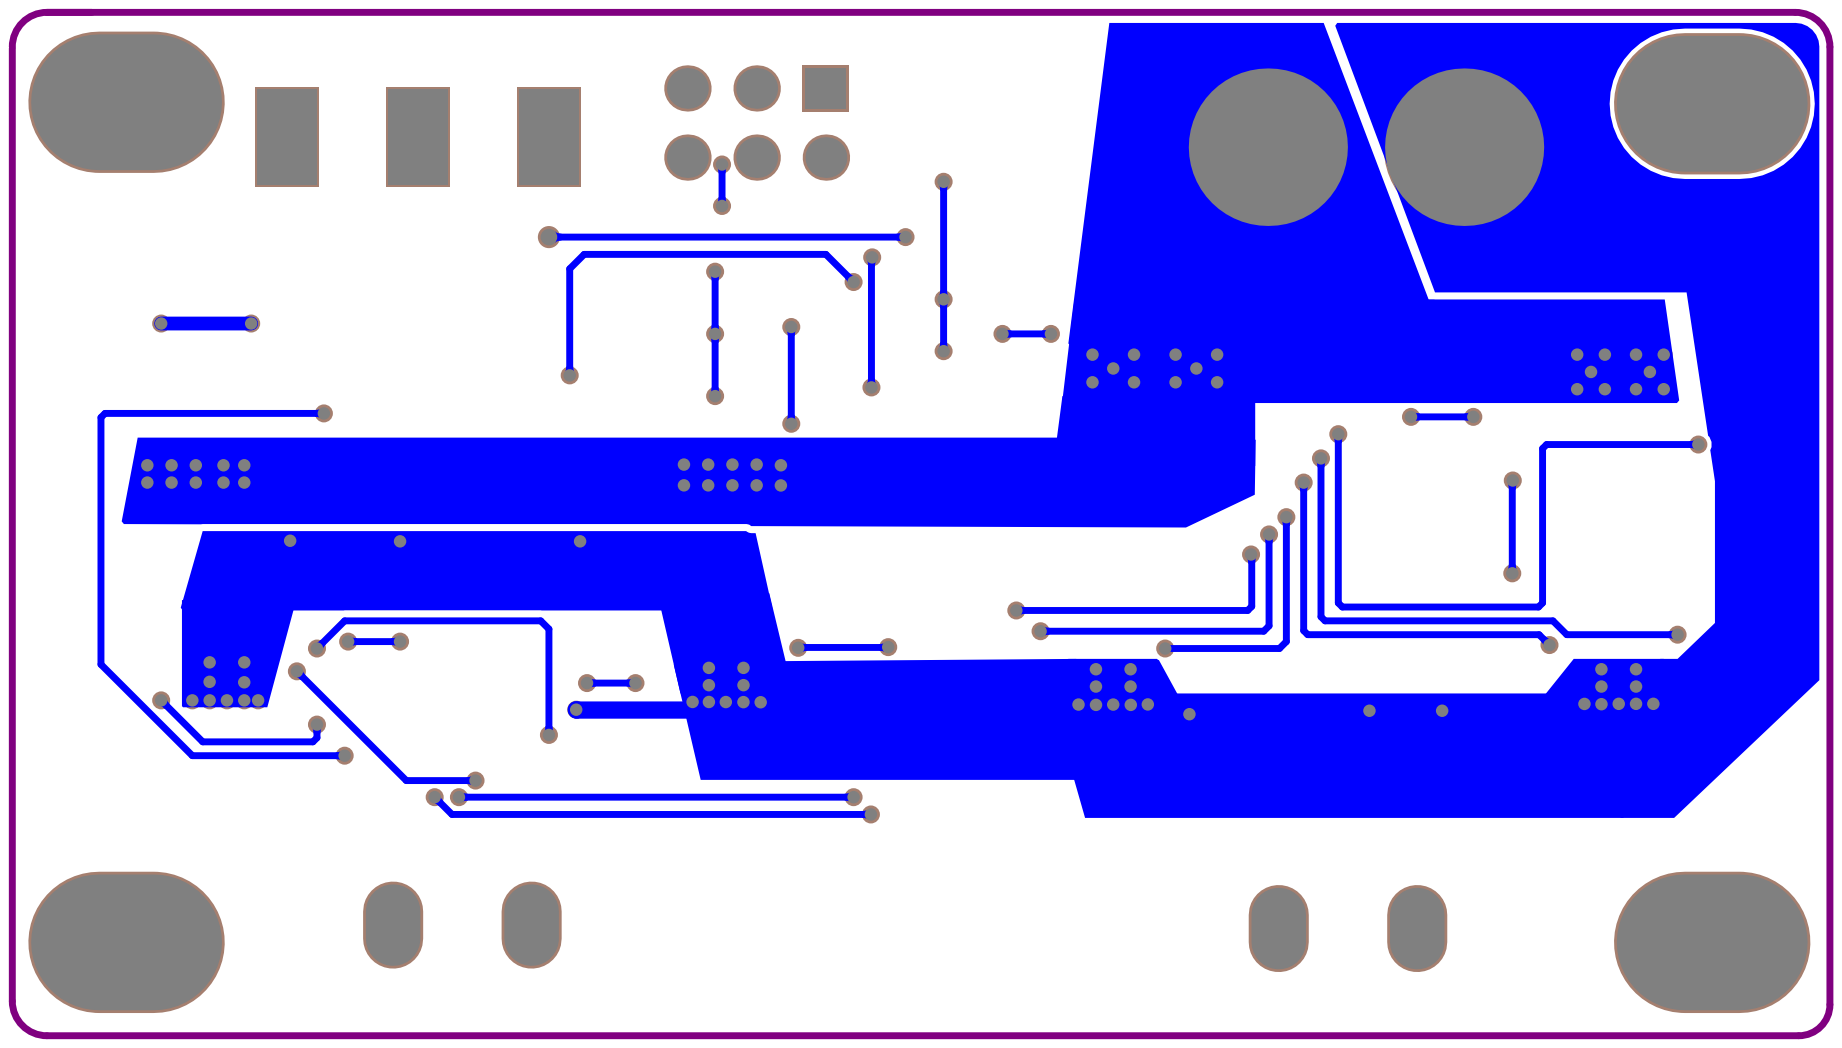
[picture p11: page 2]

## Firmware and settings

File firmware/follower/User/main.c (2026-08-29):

#include "Headfile.h"
#include "Key.h"

uint8_t KeyNum = 10;

int main(void)
{
	NVIC_PriorityGroupConfig(NVIC_PriorityGroup_2);
	OLED_Init();
	Key_Init();
	LED_Init();
	Encoder1_Init();
	Encoder2_Init();
	Servos_Init();
	PID_Init();
	Motor_Init();
	Buzzer_Init();
	Infrared_Init();
	Ultrasound_Init();
	Serial_Init();
	Timer1_Init();
	Timer4_Init();
	OLED_ShowString(1, 1, "S_Dis:");
	OLED_ShowString(1, 12, "mm");
	OLED_ShowString(2, 1, "Stop:");
	OLED_ShowString(2, 9, "Mode:");
	OLED_ShowString(4, 1, "Dis:");
	OLED_ShowString(4, 10, "mm");
	while(1) 
	{
		Display();
		if (Detection())
		{
			Mode(Modes, Set1, Set2);
		}
	}
}

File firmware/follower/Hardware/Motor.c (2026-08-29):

#include "Headfile.h"

void Motor_Init(void)
{
	RCC_APB2PeriphClockCmd(Motor_RCC, ENABLE);            //启动APB2总线上GPIOA的时钟
	
	GPIO_InitTypeDef GPIO_InitStructure;
	GPIO_InitStructure.GPIO_Mode = GPIO_Mode_AF_PP;                  //将GPIO口的输出控制权交给定时器,因此使用复用推挽输出
	GPIO_InitStructure.GPIO_Pin = R_EN_OUT | L_EN_OUT;               //PA1-RPWM,PA2-LPWM
	GPIO_InitStructure.GPIO_Speed = GPIO_Speed_50MHz;
	GPIO_Init(Motor_GPIO, &GPIO_InitStructure);
	
	GPIO_InitStructure.GPIO_Mode = GPIO_Mode_Out_PP;                 //将GPIO口的输出控制权交给定时器,因此使用复用推挽输出
	GPIO_InitStructure.GPIO_Pin = R_PH_OUT | L_PH_OUT;               //PA0-RDIR,PA3-LDIR
	GPIO_InitStructure.GPIO_Speed = GPIO_Speed_50MHz;
	GPIO_Init(Motor_GPIO, &GPIO_InitStructure);
	//对于DRV8701其输出的PWM频率需达到16kHz以上才能正常驱动电机
	
//	RCC_APB2PeriphClockCmd(Motor_RCC, ENABLE);                       //启动APB2总线上GPIOA的时钟
//	
//	GPIO_InitTypeDef GPIO_InitStructure;
//	GPIO_InitStructure.GPIO_Mode = GPIO_Mode_AF_PP;                  //将GPIO口的输出控制权交给定时器,因此使用复用推挽输出
//	GPIO_InitStructure.GPIO_Pin = FNA | FNB;                         //PA1-FNA,PA2-FNB
//	GPIO_InitStructure.GPIO_Speed = GPIO_Speed_50MHz;
//	GPIO_Init(Motor_GPIO, &GPIO_InitStructure);
//	
//	GPIO_InitStructure.GPIO_Mode = GPIO_Mode_Out_PP;
//	GPIO_InitStructure.GPIO_Pin = R_IN1 | R_IN2 | L_IN3 | L_IN4;     //PA0-RDIR,PA3-LDIR
//	GPIO_InitStructure.GPIO_Speed = GPIO_Speed_50MHz;
//	GPIO_Init(Motor_GPIO, &GPIO_InitStructure);
	
	Timer2_Init();
}

void Motor_SetSpeed1(int8_t Speed)
{
	if (Speed > 0)
	{
		GPIO_SetBits(Motor_GPIO, L_PH_OUT);                             //L_IN3 = 1
		PWM_SetCompare_Motor1(Speed);
	}
	else
	{
		GPIO_ResetBits(Motor_GPIO, L_PH_OUT);                           //L_IN3 = 0
		PWM_SetCompare_Motor1(-Speed);
	}
}

void Motor_SetSpeed2(int8_t Speed)
{
	if (Speed >= 0)
	{
		GPIO_SetBits(Motor_GPIO, R_PH_OUT);                             //R_IN1 = 1
		PWM_SetCompare_Motor2(Speed);
	}
	else
	{
		GPIO_ResetBits(Motor_GPIO, R_PH_OUT);                           //R_IN1 = 0
		PWM_SetCompare_Motor2(-Speed);
	}
}

void Motor_Status(int set1, int set2)
{
	Motor_SetSpeed1(set1);
	Motor_SetSpeed2(set2);
}


void Forward(int set1, int set2)
{
	Servos_SetAngle(90);
//	Motor_Status(set1, set2);
	Set(set1, set2);
}

void Back(int set1, int set2)
{
	Servos_SetAngle(90);
//	Motor_Status(-set1, -set2);
	Set(-set1, -set2);
}

void Cease(void)
{
	Servos_SetAngle(90);
//	Motor_Status(0, 0);
	Set(0, 0);
}

void Left_Correction(int set1, int set2, float angle)
{
	Servos_SetAngle(angle);
//	Motor_Status(set1, set2);
	Set(set1, set2);
}

void Right_Correction(int set1, int set2, float angle)
{
	Servos_SetAngle(angle);
//	Motor_Status(set1, set2);
	Set(set1, set2);
}

void Left(int set1, int set2, float angle)
{
	Servos_SetAngle(angle);
//	Motor_Status(set1, 0);
	Set(set1, set2);
}

void Right(int set1, int set2, float angle)
{
	Servos_SetAngle(angle);
//	Motor_Status(0, set2);
	Set(set1, set2);
}

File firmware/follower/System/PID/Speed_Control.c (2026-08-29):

#include "Headfile.h"

void PID_Init()
{
	Speed_Compute1.p = 1.85;              //比例系数        <= 2.65
	Speed_Compute1.i = 0.40;              //积分系数        <= 1.35
	Speed_Compute1.d = 0.0;               //微分系数--上述三个变量为PID控制系数
	Speed_Compute1.set = 0;               //设定值
	Speed_Compute1.actual = 0;            //实际值
	Speed_Compute1.err = 0;               //误差
	Speed_Compute1.l_err = 0;             //上次的误差
	Speed_Compute1.ll_err = 0;            //上上次的误差
	Speed_Compute1.increment = 0;         //增量
	Speed_Compute1.proportion = 0;        //比例
	Speed_Compute1.integral = 0;          //积分项
	Speed_Compute1.differential = 0;      //微分项
	Speed_Compute1.out = 0;               //输出
	Speed_Compute1.point_limits = 65;     //积分限度
	
	Speed_Compute2.p = 1.85;              //比例系数
	Speed_Compute2.i = 0.40;              //积分系数
	Speed_Compute2.d = 0.0;               //微分系数--上述三个变量为PID控制系数
	Speed_Compute2.set = 0;               //设定值
	Speed_Compute2.actual = 0;            //实际值
	Speed_Compute2.err = 0;               //误差
	Speed_Compute2.l_err = 0;             //上次的误差
	Speed_Compute2.ll_err = 0;            //上上次的误差
	Speed_Compute2.increment = 0;         //增量
	Speed_Compute2.proportion = 0;        //比例
	Speed_Compute2.integral = 0;          //积分项
	Speed_Compute2.differential = 0;      //微分项
	Speed_Compute2.out = 0;               //输出
	Speed_Compute2.point_limits = 65;     //积分限度
}

void Speed_Control1(int set)
{
	Speed_Compute1.set = set;
	Speed_Compute1.actual = Speed1;
	if (set == 0)
	{
		Motor_SetSpeed1(0);
		Speed_Compute1.out = 0;
		Speed_Compute1.err = 0;
		Speed_Compute1.l_err = 0;
		Speed_Compute1.ll_err = 0;
	}
	else
	{
		PID_Increment(&Speed_Compute1);
		Motor_SetSpeed1((int8_t)Speed_Compute1.out);
	}
}

void Speed_Control2(int set)
{
	Speed_Compute2.set = set;
	Speed_Compute2.actual = Speed2;
	if (set == 0)
	{
		Motor_SetSpeed2(0);
		Speed_Compute2.out = 0;
		Speed_Compute2.err = 0;
		Speed_Compute2.l_err = 0;
		Speed_Compute2.ll_err = 0;
	}
	else
	{
		PID_Increment(&Speed_Compute2);
		Motor_SetSpeed2((int8_t)Speed_Compute2.out);
	}
}

void Set(int S1, int S2)
{
	set1 = S1;
	set2 = S2;
}
